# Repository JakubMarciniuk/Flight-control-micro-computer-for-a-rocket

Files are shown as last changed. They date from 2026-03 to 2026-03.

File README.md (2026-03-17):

# Flight Control Computer (FCC) — Sounding Rocket Project

Projekt  komputera pokładowego (Flight Computer) zaprojektowanego do gromadzenia danych telemetrycznych podczas lotów rakiet modelarskich.

## 🚀 Główne Cele Projektu
* **Akwizycja danych:** Pomiar ciśnienia statycznego, temperatury oraz przyspieszenia liniowego w czasie rzeczywistym.
* **Rejestracja danych:** Zapis parametrów na kartę SD z częstotliwością 10 Hz w formacie CSV.
* **Wytrzymałość:** Konstrukcja przystosowana do pracy przy przeciążeniach rzędu 8-10 G.
* **Platforma testowa:** Zaprojektowanie rakiety nośnej oraz systemu odzysku do bezpiecznych testów elektroniki.

## 🛠 Architektura Systemu (Hardware)
Elektronika została wykonana w układzie "kanapkowym" (stack), co pozwoliło na znaczną miniaturyzację i zmieszczenie układu w korpusie o ograniczonej średnicy.

* **Jednostka obliczeniowa:** Arduino Nano (ATmega328P) taktowane zegarem 16 MHz.
* **Czujnik ciśnienia (Barometr):** MS5607 (komunikacja I2C) do precyzyjnego wyznaczania wysokości n.p.m.
* **Jednostka IMU:** MPU-6050 (3-osiowy akcelerometr i żyroskop) monitorujący dynamikę lotu.
* **Pamięć:** Moduł karty MicroSD (SPI) pełniący rolę "czarnej skrzynki".
* **Zasilanie:** Pakiet LiPo 2s 300 mAh.

## 💻 Oprogramowanie i Algorytmy
Firmware napisany w języku C++ kładzie nacisk na determinizm czasowy pętli pomiarowej.

* **Auto-kalibracja:** Przy starcie system wykonuje 50 pomiarów tła, ustalając poziom odniesienia ($H_0$) dla sensorów.
* **Fuzja danych:** Wykorzystanie modelu atmosfery wzorcowej do obliczeń wysokości:
  $$h=44330\cdot\left(1-\left(\frac{P_{aktualne}}{P_{bazowe}}\right)^{0.1903}\right)$$
* **Logowanie:** Dane są zapisywane na kartę SD w formacie CSV, co ułatwia późniejszą analizę w oprogramowaniu zewnętrznym.

## 📊 Wyniki Testów w Locie
System został zweryfikowany podczas lotu testowego z użyciem silnika klasy B4-4. Dane potwierdziły poprawność działania elektroniki w całym profilu lotu.

* **Apogeum:** Maksymalna zmierzona wysokość wyniosła 93,9 m (czas T+4,77 s).
* **Maksymalne przyspieszenie:** Akcelerometr zarejestrował fazę pracy silnika ze szczytową wartością $78,2~m/s^2$ (ok. 8 G).
* **Stabilność:** Nie odnotowano resetów mikrokontrolera ani przerw w zapisie danych mimo silnych wibracji.

| Faza lotu | Czas [s] | Wysokość [m] | Przyspieszenie Z [$m/s^2$] |
| :--- | :--- | :--- | :--- |
| Oczekiwanie | 0.00 | 0.00 | 0.05 |
| Zapłon silnika | 1.10 | 1.50 | 45.40 |
| Maksymalny ciąg | 1.20 | 5.40 | 78.20 |
| Apogeum | 5.77 | 93.90 | -9.80 |
| Opadanie (spadochron)| 15.00 | 41.00 | -0.20 |
| Przyziemienie | 22.10 | 0.00 | 4.50 |

## 📁 Struktura Repozytorium
* `/kontrola_lotu` — Pliki źródłowe firmware'u dla Arduino.
* `/Schemat_komputera_kontroli_lotu` — Schemat połączeń magistral I2C oraz SPI.
* `/FCC_raport` — Pełna dokumentacja techniczna i analiza danych.

---
*Projekt stanowi bazę do rozwoju systemów aktywnej stabilizacji lotu (np. TVC) oraz zaawansowanej telemetrii.*

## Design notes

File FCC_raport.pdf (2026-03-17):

## Spis treści

1 Cel projektu | 2
2 Projekt Systemu Elektronicznego (Flight Computer) | 2
3 Platforma Testowa (Rakieta Modelarska) | 4
4 Wyniki Testów w Locie | 5
5 Podsumowanie i Wnioski | 7

## 1 Cel projektu

Głównym celem projektu było zaprojektowanie i zbudowanie Komputera Kontroli Lotu (Flight Computer), realizującego następujące zadania:

- Pomiar parametrów fizycznych (ciśnienie statyczne, temperatura, przyspieszenie liniowe) w czasie rzeczywistym.
- Implementacja algorytmów filtracji i zapisu danych na nośnik nieulotny (karta SD) z częstotliwością próbkowania 10 Hz.
- Praca w trudnych warunkach środowiskowych (wibracje, przeciążenia rzędu 8-10G).

Celami pobocznymi było zaprojektowanie platformy nośnej (rakiety) oraz systemu odzysku, niezbędnych do przeprowadzenia bezpiecznych testów elektroniki.

## 2 Projekt Systemu Elektronicznego (Flight Computer)

Sercem projektu jest modułowy system awioniki oparty na mikrokontrolerze z rodziny AVR. Priorytetem przy projektowaniu była miniaturyzacja oraz odporność mechaniczna układu.

### 2.1 Architektura Systemu

Elektronika została zmontowana w układzie "kanapkowym"(stack), co pozwoliło na zmieszczenie jej w korpusie o ograniczonej średnicy. Schemat blokowy urządzenia obejmuje:

1. Jednostka obliczeniowa: Arduino Nano (ATmega328P) taktowane zegarem 16MHz.
2. Podsystem pomiarowy:
- MS5607 (Barometr): Precyzyjny czujnik ciśnienia (komunikacja I2C), służący do wyznaczania wysokości npm.
- MPU-6050 (IMU): 3-osiowy akcelerometr i żyroskop (komunikacja I2C), monitorujący dynamikę lotu i przeciążenia startowe.
3. Podsystem pamięci: Moduł karty MicroSD (SPI) służący jako "Czarna Skrzynka".

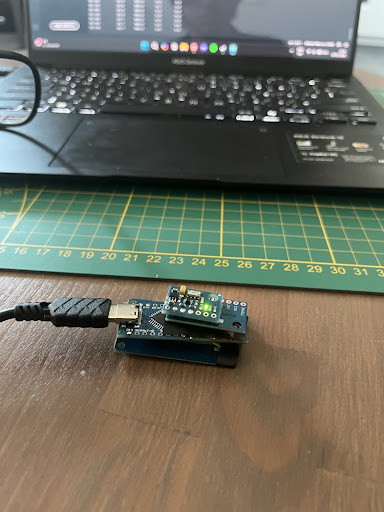
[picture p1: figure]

(a) Zintegrowany moduł komputera pokłado-

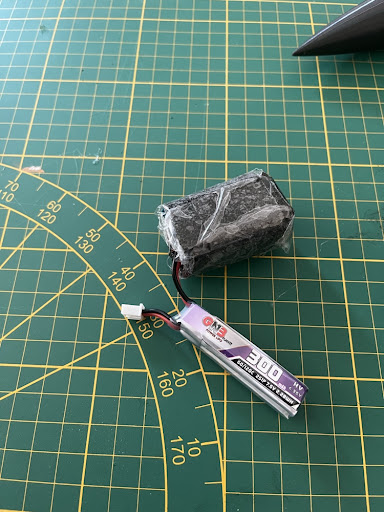
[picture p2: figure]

wego. | (b) Zasilanie LiPo 2s 300mAh.

Rysunek 1: Hardware komputera kontroli lotu oraz system zasilania.

### 2.2 Oprogramowanie i Algorytmy

Oprogramowanie (Firmware) zostało napisane w języku C++. Kluczowym wyzwaniem było zapewnienie determinizmu czasowego pętli pomiarowej.
Zaimplementowane funkcjonalności:
- Auto-kalibracja: Przy starcie system wykonuje 50 pomiarów tła, ustalając poziom odniesienia (H0) dla barometru i akcelerometru.
- Fuzja sensorów: Surowe dane są przeliczane na jednostki fizyczne. Wysokość obliczana jest z modelu atmosfery wzorcowej:

h = 44330 ·

1 −

| Paktualne Pbazowe 0.1903!
- Buforowanie danych: Zapis na kartę SD odbywa się w formacie CSV, co ułatwia późniejszą analizę w oprogramowaniu zewnętrznym (Matlab/Excel).
1 | void loop () {
2 | unsigned long czasTeraz = millis () ;
3 | // Egzekucja p t l i z c z s t o t l i w o c i | 10 Hz
4 | if ( czasTeraz - timer >= 100) {
5 | timer = czasTeraz ;

6
7 | // Odczyt z s e n s o r w
8 | float pres , temp ;
9 | czytajBarometr (& pres , & temp );
10 | // Konwersja c i n i e n i a na w y s o k o
11 | float alt = 44330.0 * (1.0 - pow ( pres / cisnienieBazowe , 0.1903) ) ;

13 | // Logowanie na n o n i k nieulotny
14 | zapiszNaKarteSD ( czasTeraz , alt , accMSS ) ;
15 | }
16 | }

Listing 1: Fragment kodu pętli głównej realizujący akwizycję danych

## 3 Platforma Testowa (Rakieta Modelarska)

W celu weryfikacji działania komputera w warunkach rzeczywistych, zaprojektowano i wykonano rakietę nośną typu "Sounding Rocket".

### 3.1 Konstrukcja

Konstrukcja hybrydowa łączy elementy kompozytowe (korpus kartonowy) z elementami wytworzonymi w technologii przyrostowej (Druk 3D FDM).

- Głowica (Nose Cone): Wydrukowana z PLA, mieści w sobie system odzysku.
- Stateczniki: Zaprojektowane w Autodesk Fusion 360, zapewniają stabilność aerodynamiczną rakiety.
- Amortyzacja: Przedział elektroniki został wyłożony pianką tłumiącej drgania wysokoczęstotliwościowe, które mogłyby zakłócić pracę akcelerometru MEMS.

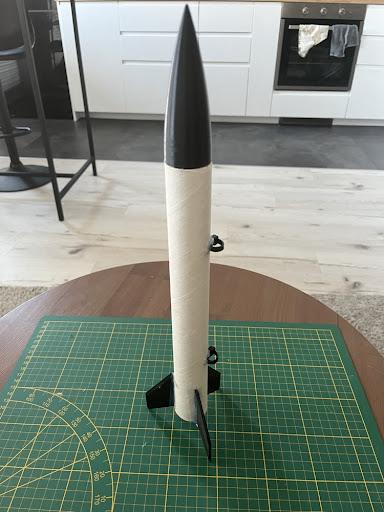
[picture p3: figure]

Rysunek 2: Rakieta testowa gotowa do lotu weryfikacyjnego.

### 3.2 System Odzysku

Rakieta została wyposażona w spadochron foliowy wyzwalany w apogeum lotu. Gwarantuje to bezpieczny powrót komputera pokładowego na ziemię w celu odczytu danych.

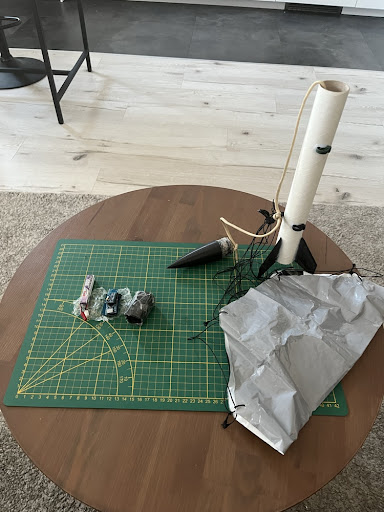
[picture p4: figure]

Rysunek 3: System odzysku zapewniający bezpieczne lądowanie elektroniki.

## 4 Wyniki Testów w Locie

Weryfikacja systemu odbyła się podczas lotu testowego z użyciem silnika klasy B4-4. Dane zarejestrowane przez komputer pokładowy zostały poddane analizie i porównane z symulacjami teoretycznymi.

### 4.1 Analiza danych telemetrycznych

Zapisane na karcie SD logi potwierdziły poprawność działania elektroniki w całym profilu lotu.

- Apogeum: Zmierzona maksymalna wysokość wyniosła 93,9 m (czas T+4,77s).
- Przeciążenia: Akcelerometr poprawnie zarejestrował fazę pracy silnika, wskazując maksymalne przyspieszenie 78,2 m/s²
(ok. 8 G).
- Stabilność: Nie odnotowano resetów mikrokontrolera ani przerw w zapisie danych, co świadczy o poprawnym projekcie zasilania.

### 4.2 Wykresy parametrów lotu

Poniższe charakterystyki wygenerowano bezpośrednio z danych surowych pobranych z komputera pokładowego.

0 | 5 | 10 | 15 | 20

0

20

40

60

80

100

Czas [s]

Wysokość [m]

Profil Wysokości zarejestrowany przez Komputer Pokładowy

Wysokość (Barometr MS5607)

Rysunek 4: Zarejestrowana zmiana wysokości. Apogeum 93,9m w ok. 5 sekundzie pomiaru.

0 | 1 | 2 | 3 | 4 | 5 | 6 | 7 | 8 | 9 | 10

−20

0

20

40

60

80

Czas [s]

Przyspieszenie [m/s

2

]

Profil Przyspieszenia Pionowego (Oś Z)

Akcelerometr MPU-6050

Rysunek 5: Zarejestrowane przeciążenia. Widoczny impuls silnika B4 (78 m/s² ) oraz moment
otwarcia spadochronu (ok. 6s).

### 4.3 Przykładowe dane pomiarowe

Aby zobrazować źródło powyższych wykresów, w Tabeli 1 przedstawiono wycinek surowych danych zapisanych na karcie SD. Wybrano 10 kluczowych próbek reprezentujących charakterystyczne etapy lotu (start, praca silnika, apogeum, lądowanie).

Tabela 1: Wybrane próbki danych z pliku lot.txt (karta SD)

Czas [s] | Wysokość [m] | Acc Z [m/s² ] | Faza lotu
0.00 | 0.00 | 0.05 | Oczekiwanie na start
1.10 | 1.50 | 45.40 | Zapłon silnika
1.20 | 5.40 | 78.20 | Maksymalny ciąg (Max G)
1.60 | 28.50 | 10.20 | Wypalenie paliwa
3.00 | 75.00 | -9.80 | Lot bezwładny
4.77 | 93.00 | -9.80 | Zbliżanie do apogeum
5.77 | 93.90 | -9.80 | Apogeum (Max Alt)
6.10 | 92.50 | 15.50 | Otwarcie spadochronu (szarpnięcie)
15.00 | 41.00 | -0.20 | Opadanie stabilne
22.10 | 0.00 | 4.50 | Przyziemienie

## 5 Podsumowanie i Wnioski

Opracowany Komputer Kontroli Lotu spełnił założenia projektowe:

1. Prawidłowo dokonał akwizycji danych w środowisku o wysokiej dynamice.
2. System zapisu na kartę SD okazał się niezawodny mimo wibracji i uderzenia przy lądowaniu.
3. Otrzymane wyniki pomiarów są spójne z modelami fizycznymi i symulacją silnika B4-4.

Rakieta pozwoliła na bezpieczne przeprowadzenie eksperymentu i odzyskanie urządzenia bez uszkodzeń. Projekt stanowi solidną bazę do rozwoju bardziej zaawansowanych systemów awioniki, np. z aktywną stabilizacją lotu.

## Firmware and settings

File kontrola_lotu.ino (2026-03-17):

#include <Wire.h>
#include <SPI.h>
#include <SD.h>

// --- KONFIGURACJA ---
const int PIN_CS_SD = 10;   // Pin karty SD
const int PIN_BUZZER = 5;   // Buzzer
#define BARO_ADDR 0x77      // Adres MS5607
#define MPU_ADDR  0x68      // Adres MPU6050

// --- ZMIENNE ---
uint16_t C[7];              // Kalibracja barometru
float cisnienieBazowe = 0;
float offsetAccZ = 0;       
unsigned long timer = 0;
File plikSD;

void setup() {
  Serial.begin(9600);
  pinMode(PIN_BUZZER, OUTPUT);
  Wire.begin();
  
  // Sygnał startu zasilania
  tone(PIN_BUZZER, 4000, 100); delay(100); noTone(PIN_BUZZER);
  Serial.println("\n=== KOMPUTER LOTU v2.2 (Z CZASEM) ===");

  // 1. KARTA SD
  Serial.print("1. Karta SD... ");
  if (!SD.begin(PIN_CS_SD)) {
    Serial.println("BLAD KARTY!");
    alarm(1);
  }
  Serial.println("OK.");
  
  // Nagłówek pliku - ZMIANA: Czas[s] zamiast ms
  plikSD = SD.open("lot.txt", FILE_WRITE);
  if (plikSD) {
    plikSD.println("Czas[s],Temp[C],Cisn[hPa],Wys[m],Acc[m/s2]");
    plikSD.close();
  }

  // 2. BAROMETR (Inicjalizacja)
  Serial.print("2. Barometr... ");
  Wire.beginTransmission(BARO_ADDR); Wire.write(0x1E); Wire.endTransmission(); delay(100);
  for (int i = 0; i < 7; i++) {
    Wire.beginTransmission(BARO_ADDR); Wire.write(0xA0 + (i * 2)); Wire.endTransmission();
    Wire.requestFrom(BARO_ADDR, 2);
    if(Wire.available()>=2) C[i] = (Wire.read() << 8) | Wire.read();
  }
  if (C[1] > 0) Serial.println("OK.");
  else { Serial.println("BLAD BAROMETRU!"); alarm(2); }

  // 3. MPU6050
  Serial.print("3. Akcelerometr... ");
  Wire.beginTransmission(MPU_ADDR); Wire.write(0x6B); Wire.write(0);
  if (Wire.endTransmission() == 0) Serial.println("OK.");
  else { Serial.println("BLAD MPU!"); alarm(3); }

  // 4. KALIBRACJA ZERA (3 sekundy)
  Serial.println("4. Kalibracja (Nie ruszaj!)...");
  float sumaP = 0, sumaA = 0;
  for(int i=0; i<50; i++) {
    float p, t;
    czytajBarometr(&p, &t);
    sumaP += p;
    sumaA += czytajAcc();
    delay(20);
  }
  cisnienieBazowe = sumaP / 50.0;
  offsetAccZ = sumaA / 50.0;
  
  Serial.println("GOTOWE. System dziala.");
  tone(PIN_BUZZER, 2000, 800); delay(800); noTone(PIN_BUZZER);
  
  Serial.println("\nMONITOR DANYCH:");
  Serial.println("Czas[s] | Temp[C] | Cisn[hPa] | Wys[m] | Acc[m/s2]");
}

void loop() {
  unsigned long czasTeraz = millis();

  // --- 1. SZYBKA FIZYKA (Dla Przyspieszenia) ---
  float accG = czytajAcc();
  float accMSS = (accG - offsetAccZ) * 9.81;
  
  // Deadzone
  if (abs(accMSS) < 0.2) accMSS = 0;
  
  // --- 2. ZAPIS I WYSWIETLANIE (Co 200ms) ---
  if (czasTeraz - timer >= 200) {
    timer = czasTeraz;

    // Przeliczenie czasu na sekundy
    float czasSekundy = czasTeraz / 1000.0;

    // Odczyt Barometru
    float pres, temp;
    czytajBarometr(&pres, &temp);
    
    // Obliczanie Wysokości
    if (pres == 0) pres = cisnienieBazowe; 
    float alt = 44330.0 * (1.0 - pow(pres / cisnienieBazowe, 0.1903));

    // A. Wyświetlanie na ekranie
    Serial.print(czasSekundy, 2); Serial.print("s   \t"); // Czas w sekundach
    Serial.print(temp, 1); Serial.print("\t  ");
    Serial.print(pres, 1); Serial.print("\t      ");
    Serial.print(alt, 1);  Serial.print("\t ");
    Serial.println(accMSS, 1);

    // B. Zapis na kartę SD
    plikSD = SD.open("lot.txt", FILE_WRITE);
    if (plikSD) {
      plikSD.print(czasSekundy, 2); plikSD.print(","); // Zapisujemy sekundy
      plikSD.print(temp, 2);   plikSD.print(",");
      plikSD.print(pres, 2);   plikSD.print(",");
      plikSD.print(alt, 2);    plikSD.print(",");
      plikSD.println(accMSS, 2);
      plikSD.close();
    }
  }
}

// --- FUNKCJE ---

void alarm(int n) {
  while(true) {
    for(int i=0; i<n; i++) { tone(PIN_BUZZER, 1000, 200); delay(300); }
    delay(1000);
  }
}

float czytajAcc() {
  Wire.beginTransmission(MPU_ADDR); Wire.write(0x3B + 4); Wire.endTransmission(false);
  Wire.requestFrom(MPU_ADDR, 2, true);
  int16_t raw = Wire.read()<<8 | Wire.read();
  return raw / 16384.0;
}

void czytajBarometr(float *p, float *t) {
  uint32_t D1=0, D2=0;
  
  Wire.beginTransmission(BARO_ADDR); Wire.write(0x48); Wire.endTransmission(); delay(10);
  Wire.beginTransmission(BARO_ADDR); Wire.write(0x00); Wire.endTransmission();
  Wire.requestFrom(BARO_ADDR, 3);
  if(Wire.available()>=3) D1 = ((uint32_t)Wire.read()<<16)|((uint32_t)Wire.read()<<8)|Wire.read();
  
  Wire.beginTransmission(BARO_ADDR); Wire.write(0x58); Wire.endTransmission(); delay(10);
  Wire.beginTransmission(BARO_ADDR); Wire.write(0x00); Wire.endTransmission();
  Wire.requestFrom(BARO_ADDR, 3);
  if(Wire.available()>=3) D2 = ((uint32_t)Wire.read()<<16)|((uint32_t)Wire.read()<<8)|Wire.read();

  if (D1 == 0 || D2 == 0) {
    *p = cisnienieBazowe; 
    *t = 0;
    return;
  }

  int64_t dT = (int64_t)D2 - ((int64_t)C[5] << 8);
  int64_t TEMP = 2000 + ((int64_t)dT * C[6]) / 8388608;
  int64_t OFF = ((int64_t)C[2] << 17) + (((int64_t)C[4] * dT) >> 6);
  int64_t SENS = ((int64_t)C[1] << 16) + (((int64_t)C[3] * dT) >> 7);
  int64_t P = (((D1 * SENS) >> 21) - OFF) >> 15;
  
  *t = (float)TEMP / 100.0;
  *p = (float)P / 100.0;
}
